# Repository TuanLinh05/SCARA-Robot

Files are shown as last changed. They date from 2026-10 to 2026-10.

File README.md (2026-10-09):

# SCARA Drawing Robot

A 2R + Z pen-drawing robot with STM32/Zephyr firmware, a Python Cartesian GUI, and MATLAB/Simulink + Webots models.

[English](#english) | [Tiếng Việt](#tieng-viet)

<p align="center">
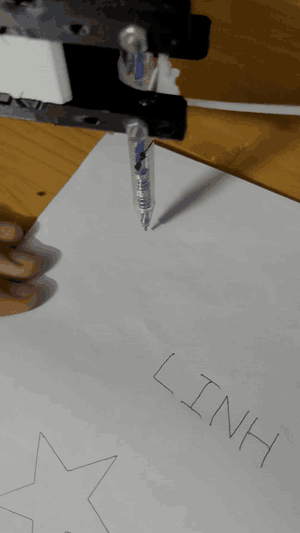
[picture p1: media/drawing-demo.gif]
Real SCARA robot drawing a six-petal flower beside earlier LINH and star drawings
  
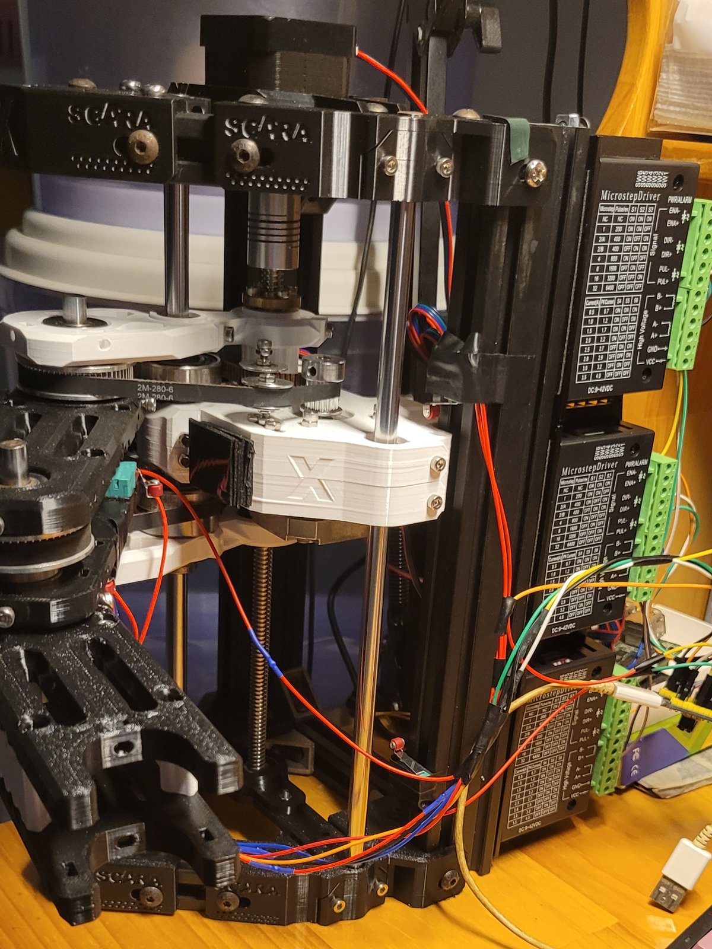
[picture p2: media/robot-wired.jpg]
Assembled X-SCARA frame, belt-driven arms, vertical lead screw, and three stepper drivers
  
</p>

The checked-in drawing demo is shown at 2x speed. [Original video](media/drawing-demo.mp4) | [Side view](media/robot-side-1.jpg) | [Driver reference photo](media/tb6600-driver.jpg).

SCARA system diagram showing GUI protocol 5, STM32 firmware R9, TB6600 drivers, six limit switches, and separate MATLAB/Webots simulation

## English

This HPMR course project (HK261) controls a SCARA robot that draws shapes and text on paper. Two rotary joints position the pen in XY and a vertical lead-screw axis raises or lowers the arm assembly. The PC performs kinematics and path planning; the STM32 emits coordinated step pulses and handles homing, limits, and communication faults.

**The frame and arm mechanics originate from [madl3x/X-SCARA](https://github.com/madl3x/x-scara/tree/master), GPL-3.0.** The STL files, mechanical BOMs, and assembly images in `Hardware/arm`, `Hardware/frame`, and `Hardware/3D Print` retain that attribution. This project's additions include firmware, GUI, simulation, and a Deli EG118 pen holder fitted to the reference geometry.

### Current components

| Component | Current version / role |
| --- | --- |
| Physical controller | STM32F103C8 Blue Pill, USB CDC, Zephyr 3.7 |
| Firmware | `SCARA_CART_NC_HOME_V5_R9`, protocol 5 |
| Desktop GUI | R14, Python 3.12 + Tkinter + pyserial |
| Stepper system | Three NEMA 17 motors and TB6600 STEP/DIR drivers |
| Homing | Six COM-NC limit switches, two per axis |
| Mechanical defaults | L1/L2 98 mm, Z lead 2 mm/revolution, configured microsteps Z/J1/J2 = 16/8/8 |
| Simulation | Analytical MATLAB/Simulink model and a separate Webots rigid-body model |

Mechanical numbers are **configuration defaults**, not measurements of every assembled robot. The real robot has no encoder-based position feedback. Its displayed Cartesian position is derived from the firmware's emitted pulse counts.

### What the system does

- Cartesian jogging, forward/inverse kinematics, reach checking, mechanical-model editing, and test point sequences.
- Shape/text library including BK, LINH, THOA, flower, star, heart, circle, ellipse, square, triangle, and rhombus.
- Whole-stroke preflight before uploading `PATH` / `SEG` / `GO` commands to a 32-segment firmware FIFO.
- Coordinated three-axis DDA step generation using a 1 MHz TIM2 timebase and fixed-point velocity profiles. The timebase is not a 1 MHz motor step rate.
- HOME/CALIB sweeps and a measured elbow-coupling probe; GPIO checks, soft limits, USB/heartbeat monitoring, and buffer-underrun handling.
- JSONL session logging and offline drawing audits.
- A `--demo` GUI mode that uses a simulated link without opening a real COM port.

### Repository map

| Path | Contents |
| --- | --- |
| [Firmware/ScaraCartesian](Firmware/ScaraCartesian) | Active Zephyr source, host tests, build tools, and supplied HEX/BIN |
| [Firmware/Ref](Firmware/Ref) | Original STM32CubeIDE/HAL project retained as reference |
| [Software/src](Software/src) | GUI, kinematic model, protocol, path planning, shapes, logs, audits |
| [Software/tests](Software/tests) | Python tests and GUI smoke checks using simulated ports |
| [Software/packaging](Software/packaging) | R14 PyInstaller specification |
| [Simulation/common](Simulation/common) | Shared SI parameters, CSV trajectories, converted meshes, provenance |
| [Simulation/matlab](Simulation/matlab) | MATLAB app, dynamics/control modules, editable Simulink model |
| [Simulation/webots](Simulation/webots) | World, PROTOs, Python controller, builder, offline checks |
| [Hardware](Hardware) | X-SCARA print files/BOMs/assembly images and EG118 holder |
| [Doc](Doc) | Firmware review and discussion of drawing errors |
| [media](media) | Photos and drawing demonstration of the physical robot |

### Try the GUI without hardware

From the repository root on Windows, with Python 3.12 and Tkinter available:

```powershell
git clone https://github.com/TuanLinh05/SCARA-Robot.git
cd SCARA-Robot
py -3.12 -m pip install -r Software\requirements.txt
py -3.12 Software\src\cartesian_nc_control.py --demo
```

The runtime requirement file pins `pyserial==3.5`; Tkinter is part of the Python environment. Demo mode lets you inspect the GUI flow without serial hardware, but it does not validate motor behavior or drawing accuracy.

For the physical connection, omit `--demo`:

```powershell
py -3.12 Software\src\cartesian_nc_control.py
```

Alternatively, `Software/Run_Cartesian_GUI.bat` uses an existing R14 EXE if present, otherwise tries a configured Zephyr Python environment and then `py -3`. A fresh clone does not include `Software/dist`.

To package the GUI from the root:

```powershell
.\Software\Build_Cartesian_NC_GUI.ps1 -Python python
```

The script can install its build dependencies into `Software/.packaging` and produces `Software/dist/SCARA_Cartesian_NC_v5_R14`. Keep the EXE and its `_internal` directory together. See [Software/README.md](Software/README.md) for configuration/log locations and the module organization.

### Wiring

The TB6600 input arrangement is common-cathode: **PUL-, DIR-, and ENA- connect to shared GND**. Check the actual driver's input characteristics and current/microstep settings against your board and motors.

| Axis | PUL+ | DIR+ | ENA+ | DIR HIGH-end switch | DIR LOW-end switch |
| --- | --- | --- | --- | --- | --- |
| Z | PA0 | PA1 | PA2 | PA3, top | PA4, bottom |
| J1 | PA8 | PB15 | PB14 | PB0 | PB1 |
| J2 | PA6 | PA7 | PB13 | PB10 | PB11 |

The [Zephyr overlay](Firmware/ScaraCartesian/app.overlay) configures ENA outputs active LOW. Switches use **COM -> GND, NC -> GPIO**, with internal 3.3 V pull-ups; NO is unused. Normal closed wiring reads LOW, while an actuated switch or open wire reads HIGH.

USB CDC uses the Blue Pill's micro-USB port: PA11 D-, PA12 D+. The GUI opens the virtual COM port at the configured 115200 baud; no separate USB-UART console is used by the active firmware.

Assembly resources: [print list](Hardware/3D%20Print/README.md), [arm BOM](Hardware/arm/BOM.md), [frame BOM](Hardware/frame/BOM.md), and [EG118 pen holder](Hardware/Pen_Holder_EG118/README.md). The print collection is organized as 14 frame parts, 23 arm parts, and one test part.

### Firmware build and supplied images

The current images are [SCARA_Cartesian_NC_Home_v5_R9.hex](Firmware/ScaraCartesian/Hex/SCARA_Cartesian_NC_Home_v5_R9.hex) and [the matching named BIN](Firmware/ScaraCartesian/Hex/SCARA_Cartesian_NC_Home_v5_R9.bin). The documented flash base is `0x08000000`; use an ST-Link/programmer configured for the actual STM32F103C8 board.

The source build expects Zephyr 3.7, Zephyr SDK 0.16.8, CMake, Ninja, and a Python/Zephyr workspace. The PowerShell helper accepts installation-path overrides:

```powershell
# Example paths: replace with your Zephyr workspace and SDK locations.
.\Firmware\ScaraCartesian\tools\build.ps1 `
  -ZephyrRoot D:/zephyrproject `
  -SdkRoot D:/zephyr-sdk/zephyr-sdk-0.16.8 `
  -BuildDirectory build_refactor -SkipExport
```

It builds board `stm32_min_dev@blue` and creates/checks a `scara_cartesian_workspace` junction under the Zephyr workspace to avoid paths with spaces. `-SkipExport` leaves the supplied `Hex` directory untouched; without it, the helper exports new HEX/BIN images there. Read [the firmware guide](Firmware/ScaraCartesian/README.md) before building or programming a board.

The GUI parser requires firmware build `SCARA_CART_NC_HOME_V5_R9` and protocol-5 status. A connected port alone does not establish firmware compatibility.

### Home, calibration, and drawing

1. Connect the correct COM port and confirm the firmware tag.
2. Review **Cơ khí** (Mechanics): link lengths, lead, microsteps, switch angles, direction signs, and tool offset must reflect the assembled robot.
3. Use **HOME / CALIB** to establish a reference. The routine scans Z/J2, probes J1-to-J2 coupling, scans J1 with compensation, then finishes the joint reference and park position.
4. Bring the pen just into contact and capture/confirm **Z giấy** (paper Z).
5. Choose **Thư viện hình & chữ** (Shape & text library), set size/center, and run **Chạy khô** (dry run) before drawing.
6. Following STOP/Esc, a reset, communication failure, limit fault, or loss of reference, HOME again before further motion.

Default `positive_high=[true,true,false]` accounts for J2's direction convention. Do not reverse signs without checking the mechanism. `tool_offset_mm=[x,y]` represents pen-tip offset from the end of L2; avoid counting the same offset in both L2 and this vector. Save mechanical changes and HOME again.

Calibration measures pulse travel and coupling. **It does not discover the true physical switch angles, link lengths, pen deflection, or missed motor steps.** Enter measured geometry instead of assuming the nominal ±90-degree switch positions are exact.

The firmware checks switch state on pulse edges, enforces soft limits, and uses a 350 ms heartbeat watchdog. Motion/arm paths are capped at 1600 pulses/s; Z calibration has a separate ceiling. These are code limits, not verified speed/accuracy specifications. Faults invalidate the reference and do not automatically resume a job.

### MATLAB/Simulink and Webots

Both models use [Simulation/common/config/scara.json](Simulation/common/config/scara.json) and shared drawing CSVs. Simulation parameters use SI units; `example_drawing.csv` uses `x_mm,y_mm,pen`, with each row's pen state applying to the segment from the previous row.

| Environment | Entry point | Requirements / limits |
| --- | --- | --- |
| MATLAB | Set Current Folder to `Simulation/matlab`, run `run_scara` | Base MATLAB supports the app/analytical model; Robotics System Toolbox and Simscape Multibody are not required |
| Simulink | `startup_scara; out=scara_simulink('flower');` | Simulink is required for the `.slx` model |
| Webots | Open `Simulation/webots/worlds/scara_draw.wbt`, then Run | Python 3 standard-library controller; no ROS or NumPy requirement |

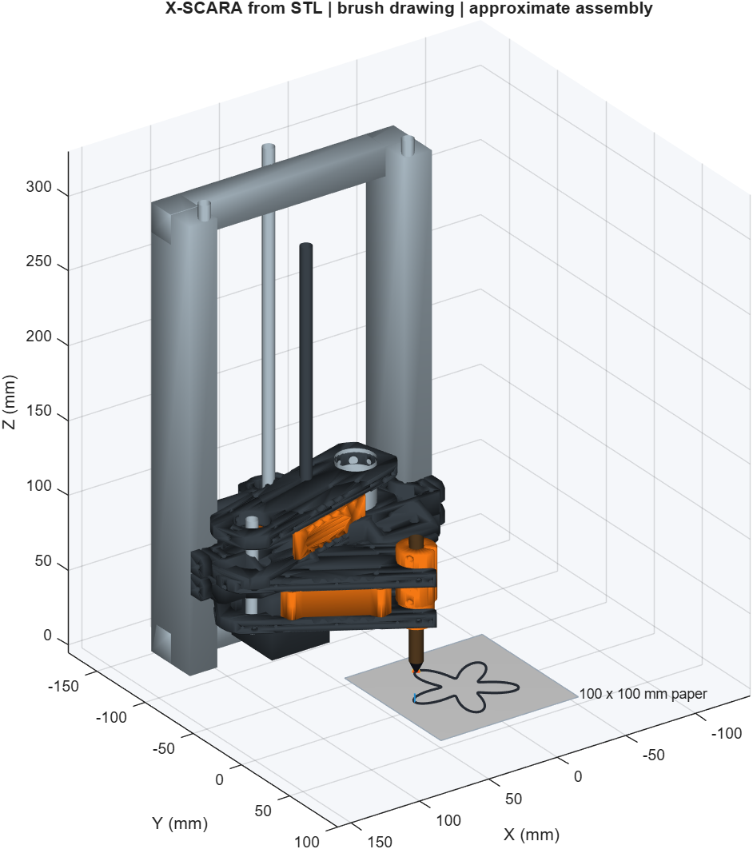
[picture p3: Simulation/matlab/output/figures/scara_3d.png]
Existing MATLAB simulation render of the X-SCARA arm and drawing surface


The MATLAB guide records execution on R2026a Update 2. Webots assets use the R2025a format; the checked-in guide reports offline/mock validation and leaves actual Webots physics execution unconfirmed. Offline checks are not evidence of a successful physical simulation run.

Webots `config/demo.json` selects `flower`, `circle`, `square`, or `csv`, and `position` or `pid` control. MATLAB analytical dynamics and Webots rigid-body/contact dynamics are different plants. Mesh geometry, inertias, simplified collisions, and brush stiffness/friction need calibration before comparing with hardware.

### Checks, logs, and accuracy limits

Existing verification entry points, from the repository root:

```powershell
# Host C firmware harness, then software tests; GUI checks use simulated ports.
.\Verify_SCARA.ps1 -Python python -Gcc gcc -Gui

# Webots offline checks; this does not launch the Webots simulator.
python -m unittest discover -s Simulation/webots/tests -v
```

The host firmware checks require GCC. The scripts may generate build/cache files. These commands are available to developers; no runtime tests or hardware operation are implied by this README update.

To inspect a saved session without opening COM:

```powershell
python Software/src/cartesian_nc_audit.py path/to/session.jsonl --out Software/reports/drawing_audit
```

The logs describe commands, timing, queue state, and pulse-coordinate telemetry. They cannot detect physical missed steps, belt backlash, paper movement, or pen flex. A correct final pulse count does not prove that the pen reached the requested point.

For distorted drawings, measure switch angles, motor/DIP settings, link lengths, and tool offset; compare lower and higher speeds with light pen pressure; inspect belt tension and holder rigidity. The [dated firmware review](Doc/Danh_gia_Firmware_SCARA.md) and [drawing audit](Software/reports/drawing_audit_20261008.md) provide diagnostic context. Their pulse/log inferences should not be treated as direct measurements of pen accuracy or automatically applied to every configuration.

### Documentation, credits, and license

Detailed component guides are primarily Vietnamese: [firmware](Firmware/ScaraCartesian/README.md), [GUI](Software/README.md), [simulation overview](Simulation/README.md), [MATLAB](Simulation/matlab/README.md), and [Webots](Simulation/webots/README.md).

- Frame/arm STL, BOMs, and assembly images: [madl3x/x-scara](https://github.com/madl3x/x-scara/tree/master), by [@madl3x](https://github.com/madl3x), source commit `3c7c17e`, GPL-3.0.
- Simulation mesh conversions record sources/hashes in [manifest.json](Simulation/common/assets/manifest.json).
- Pen-holder source and derivative reference geometry are described in [NOTICE.txt](Hardware/Pen_Holder_EG118/NOTICE.txt) and [SOURCE_LICENSE.txt](Hardware/Pen_Holder_EG118/SOURCE_LICENSE.txt).
- `Firmware/Ref` retains generated STM32CubeMX/HAL code and STMicroelectronics notices.

The repository is released under [GNU GPL v3.0](LICENSE). Project author: [Vu Tuan Linh](https://github.com/TuanLinh05), HPMR / HK261.

## Tiếng Việt

Project môn HPMR (HK261) điều khiển robot SCARA vẽ hình/chữ lên giấy. Hai khớp quay tạo chuyển động XY, trục Z nâng/hạ cụm tay. GUI tính động học và lập đường đi; STM32 phát xung phối hợp, HOME và giám sát lỗi.

**Khung và tay robot lấy từ [X-SCARA của madl3x](https://github.com/madl3x/x-scara/tree/master), GPL-3.0.** STL, BOM và ảnh lắp ráp giữ ghi nhận nguồn này. Phần bổ sung gồm firmware, GUI, mô phỏng và giá bút EG118; mesh/giá bút có manifest và NOTICE nguồn.

### Chạy GUI và kết nối

Phiên bản hiện tại: GUI R14, firmware `SCARA_CART_NC_HOME_V5_R9`, protocol 5, Blue Pill STM32F103C8 và Zephyr 3.7. GUI dùng Python 3.12, Tkinter và pyserial 3.5.

Từ gốc repo:

```powershell
py -3.12 -m pip install -r Software\requirements.txt
py -3.12 Software\src\cartesian_nc_control.py --demo
```

`--demo` dùng cổng giả lập, không mở COM thật. Bỏ cờ này để chạy GUI kết nối robot. `Software/Run_Cartesian_GUI.bat` ưu tiên EXE đã có, rồi thử Python; bản clone mới không có `Software/dist`. Lệnh đóng gói và build firmware ở phần tiếng Anh nhận đường dẫn công cụ theo máy của bạn.

### Đấu dây và HOME

TB6600 nối chung âm PUL-/DIR-/ENA- về GND. Bảng chân đầy đủ ở phần tiếng Anh: Z dùng PA0/PA1/PA2; J1 dùng PA8/PB15/PB14; J2 dùng PA6/PA7/PB13. USB CDC qua PA11 D-/PA12 D+, không cần USB-UART riêng. Công tắc COM -> GND, NC -> GPIO kéo lên 3.3 V; bình thường LOW, chạm/hở dây HIGH.

1. Chọn COM và xác nhận firmware R9/protocol 5.
2. Kiểm tra **Cơ khí**: L1/L2, lead Z, vi bước, góc công tắc, dấu chiều và lệch đầu bút.
3. HOME / CALIB, sau đó lấy/xác nhận Z giấy khi bút vừa chạm.
4. Chọn hình/chữ, cỡ và tâm; chạy khô trước khi vẽ.
5. Dừng/Esc, mất USB/heartbeat, lỗi biên hoặc reset làm mất mốc; cần HOME lại.

L1/L2 98 mm, lead 2 mm/vòng và vi bước 16/8/8 là mặc định cấu hình. HOME đo số xung và hệ số ghép, **không tự đo góc công tắc thật hoặc vị trí ngòi bút**. Đừng cộng cùng một độ lệch vào cả L2 và `tool_offset_mm`. Sau khi đổi cơ khí, lưu rồi HOME lại.

### Mô phỏng, log và giới hạn

- MATLAB: vào `Simulation/matlab`, chạy `run_scara`; Simulink cần cho file SLX. Tài liệu ghi nhận chạy trên R2026a Update 2.
- Webots: mở `Simulation/webots/worlds/scara_draw.wbt`, nhấn Run. Controller chỉ cần thư viện chuẩn Python; world dùng format R2025a. Tài liệu hiện chỉ xác nhận kiểm tra offline/mock, chưa xác nhận chạy vật lý Webots thật.
- Hai môi trường chia sẻ tham số SI và CSV trong `Simulation/common`; mô hình động lực học/tiếp xúc khác nhau và còn dùng thông số ước lượng.
- `Verify_SCARA.ps1 -Gui` chạy harness firmware trên máy rồi các kiểm thử GUI bằng cổng giả lập; không điều khiển robot. GCC cần cho harness.
- Công cụ `cartesian_nc_audit.py` đọc JSONL mà không mở COM. Log ghi lệnh và tọa độ xung, không đo mất bước, độ rơ, bút võng hoặc giấy dịch.

Robot thật **không có encoder**. Số xung đúng không chứng minh đầu bút đã tới đúng điểm. Khi hình lệch/méo, đo lại góc biên và chiều dài/offset, kiểm tra DIP driver, đai và giá bút; so sánh tốc độ thấp/cao với lực tì nhẹ. Các kết luận trong [đánh giá firmware](Doc/Danh_gia_Firmware_SCARA.md) là ngữ cảnh chẩn đoán cho log/cấu hình tại thời điểm đó, không phải phép đo độ chính xác cho mọi robot.

Repo phát hành theo [GNU GPL v3.0](LICENSE). Giữ ghi nhận [madl3x/X-SCARA](https://github.com/madl3x/x-scara) và giấy phép nguồn khi dùng lại. Tác giả project: [Vu Tuan Linh](https://github.com/TuanLinh05), HPMR / HK261.

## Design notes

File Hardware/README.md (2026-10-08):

# Hardware

> **Nguồn:** khung và tay robot lấy từ dự án mã nguồn mở
> [madl3x/x-scara](https://github.com/madl3x/x-scara/tree/master)
> (tác giả [@madl3x](https://github.com/madl3x), commit `3c7c17e`, giấy phép GPL-3.0).
> Mọi file STL, BOM và ảnh trong `arm/`, `frame/`, `3D Print/` thuộc dự án đó;
> nhóm chỉ sắp xếp lại theo màu/số lượng in và dịch hướng dẫn.

| Thư mục | Nội dung | Nguồn |
| --- | --- | --- |
| [`frame/`](frame) | STL khung, [BOM](frame/BOM.md), ảnh lắp ráp | X-SCARA |
| [`arm/`](arm) | STL tay (base, shoulder, elbow, endstop), [BOM](arm/BOM.md), ảnh lắp ráp | X-SCARA |
| [`3D Print/`](3D%20Print) | Cùng các STL trên, xếp theo màu và số bản cần in | X-SCARA (sắp xếp lại) |
| [`Pen_Holder_EG118/`](Pen_Holder_EG118) | Giá kẹp bút Deli EG118: SCAD, Python, STL | Tự thiết kế, dẫn xuất từ STL X-SCARA |

Thông tin cơ khí đầy đủ và bản thiết kế mới nhất: xem repo gốc
[madl3x/x-scara](https://github.com/madl3x/x-scara/tree/master).

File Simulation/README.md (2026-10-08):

# Mô phỏng X-SCARA vẽ bằng bút lông

Hai môi trường dùng chung hình học, tham số SI và CSV quỹ đạo. MATLAB/Simulink
dùng mô hình giải tích để nghiên cứu thuật toán; Webots dùng vật lý vật rắn,
tiếp xúc đầu bút và giấy, cùng thiết bị Pen để hiển thị nét.

## Tìm file nhanh

```text
Simulation/
├── common/
│   ├── config/scara.json              Thông số robot/bút dùng chung
│   ├── trajectories/                 CSV đường vẽ
│   └── assets/                       Mesh theo khâu, giấy, nguồn/giấy phép
├── matlab/
│   ├── run_scara.m                    Mở giao diện MATLAB
│   ├── startup_scara.m                Thêm đường dẫn + đặt cache
│   ├── config/                       Đọc tham số chung
│   ├── src/                          kinematics, dynamics, control,
│   │                                 trajectory, simulation, io, visualization
│   ├── simulink/models/              scara_brush.slx
│   ├── examples/                     So sánh PID, đọc log Webots
│   ├── tests/                        Kiểm chứng MATLAB/Simulink
│   └── output/                       figures, data, logs, validation, cache
└── webots/
    ├── worlds/scara_draw.wbt          Mở file này trong Webots
    ├── protos/                       Robot SCARA và mặt giấy
    ├── controllers/scara_draw/       Entry point + core/ thuật toán
    ├── config/demo.json              Chọn hình, chế độ điều khiển, màu mực
    ├── tools/                        Tạo lại dự án, kiểm tra offline
    ├── tests/                        Động học, điều khiển, cấu trúc, I/O
    └── output/                       runs/<thời điểm>/, validation/
```

## Chạy Webots

1. Cài Webots và Python 3. Không cần NumPy hay ROS cho controller này.
2. Mở [webots/worlds/scara_draw.wbt](webots/worlds/scara_draw.wbt) bằng **File → Open World**.
3. Nhấn **Run**. Robot di chuyển đến điểm đầu, hạ bút, vẽ hoa rồi nhấc bút.
4. Sửa [webots/config/demo.json](webots/config/demo.json), sau đó **Reset/Reload**
   để thử `circle`, `square`, `csv` hoặc `control_mode: "pid"`.

Xem [hướng dẫn Webots](webots/README.md) để chỉnh thuật toán, đọc log và debug.
World/PROTO dùng header `R2025a`, bản ổn định chính thức được kiểm tra ở thời điểm
tạo dự án. Không cần đổi header chỉ vì cài một bản mới hơn. Máy hiện chưa có
Webots nên chưa xác nhận khởi chạy hoặc vật lý trên bản 2026 bạn định cài.

## Chạy MATLAB/Simulink

Trong MATLAB, chuyển Current Folder đến `Simulation/matlab` rồi chạy:

```matlab
run_scara
```

Hoặc `startup_scara; out=scara_simulink('flower');`. File SLX nằm trong
`matlab/simulink/models/scara_brush.slx`, tự thêm đường dẫn khi mở/chạy trực tiếp.
Xem [hướng dẫn MATLAB](matlab/README.md).

## Các điểm cần biết trước khi dùng kết quả trong bài tập

- Hình dáng tay lấy từ 11 instance STL trong `Hardware/arm/STL`, gom thành
  5 mesh có đơn vị mét. Chiều dài hai khâu mặc định 98 mm. Tầng lắp ráp Z,
  thành bên, khung, motor, bút và giá kẹp còn là xấp xỉ.
- Mô hình có hai khớp quay và trục Z nâng cả cụm tay. Webots có thêm khớp
  đàn hồi thụ động ở đầu bút, GPS đầu bút, cảm biến lực và encoder.
- Khối lượng, quán tính, ma sát, giới hạn khớp/lực và độ đàn hồi cần hiệu chỉnh
  bằng đo đạc. STL chỉ cung cấp bề mặt; không tự chứa các thông số này.
- Bút dùng tiếp xúc cầu nhỏ + lò xo để nghiên cứu lực tì. Nét Pen có độ rộng
  cố định; chưa mô phỏng từng sợi bút, mực loang hoặc nét thư pháp.
- Collision dùng hình đơn giản và `selfCollision FALSE`; chưa kiểm chứng tránh
  va chạm chi tiết. Đai/crosstalk chỉ được quy đổi tọa độ A/B trong log, chưa
  được mô phỏng như truyền động đàn hồi hay mô hình điện động cơ bước.

## Trạng thái kiểm chứng

MATLAB/Simulink đã chạy thực tế trên R2026a Update 2 sau khi sắp xếp lại thư mục.
Kiểm thử Webots offline kiểm tra thuật toán, đối chiếu MATLAB, I/O controller,
trường node theo nguồn R2025a, đường dẫn mesh và tính nhất quán khớp/quán tính.
Kiểm thử mock không mô phỏng vật lý Webots. Kết quả nằm trong `output/validation`
của từng môi trường; phần chạy Webots thật còn chờ cài phần mềm.

Nguồn thiết kế: [madl3x/x-scara](https://github.com/madl3x/x-scara), GPL-3.0.
Mesh chuyển đổi giữ manifest nguồn, mã băm và giấy phép trong `common/assets`.
Tài liệu [Pen](https://cyberbotics.com/doc/reference/pen),
[khớp](https://cyberbotics.com/doc/reference/jointparameters),
[TouchSensor](https://cyberbotics.com/doc/reference/touchsensor) và
[bản phát hành Webots](https://github.com/cyberbotics/webots/releases).

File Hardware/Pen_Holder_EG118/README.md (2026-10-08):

# Giá giữ bút Deli EG118 cho đầu SCARA — bản 1

Đã dựng theo hai STL `Arm_Elbow_Plate_Top_1.0.0.stl`, `Arm_Elbow_Plate_Bottom_1.0.0.stl` và chiều cao 18 mm của sidewall trong `Hardware/arm`. Thân bút lấy theo số đo bạn cung cấp: **khoảng 9 mm**, có thể sai ±0,5 mm.

Giá gồm thân gá vào hai ngàm chữ U và một nắp ép bút vào rãnh V 90°. Hai mặt V cùng mặt ép tạo ba hướng tiếp xúc, giúp căn bút thẳng. Hai ốc xuyên ngang giữ giá vào robot; bốn ốc riêng siết nắp giữ bút. Có thể nới nắp để chỉnh độ thò ngòi hoặc thay bút. Khoảng đường kính đã kiểm tra hình học: **8,5–9,5 mm**.

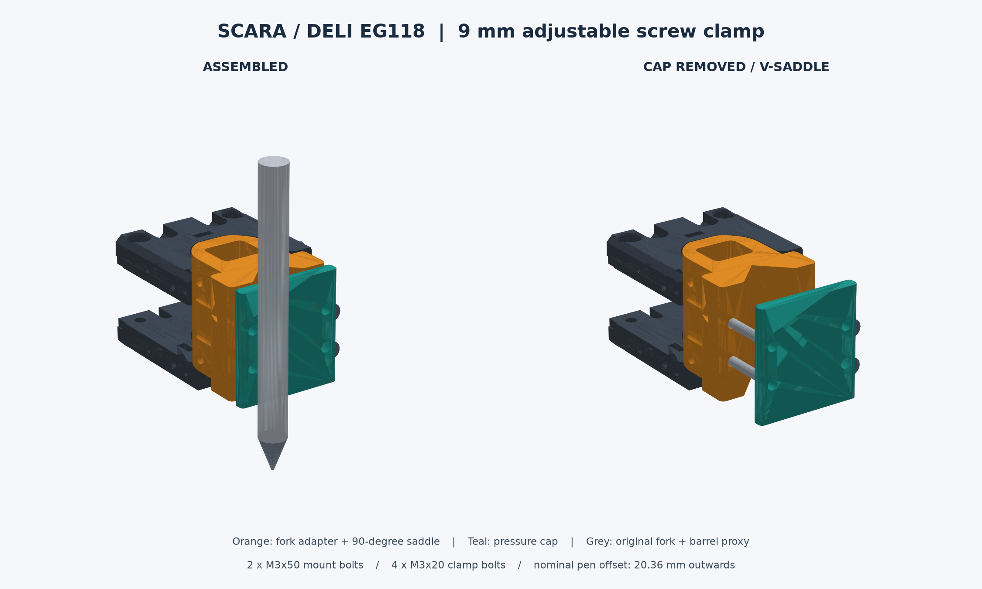
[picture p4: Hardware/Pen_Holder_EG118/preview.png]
Hình lắp ráp


## File để in

| File trong `STL/` | Số lượng | Công dụng | Kích thước đặt trên bàn in, mm |
| --- | ---: | --- | --- |
| `01_Fork_Adapter_V_Saddle.stl` | 1 | Thân gá và rãnh V | 34 × 34,6 × 36 |
| `02_Pressure_Cap.stl` | 1 | Nắp ép bút | 34 × 36 × 4 |
| `03_Test_Adapter_8mm.stl` | 1, nên in trước | Mẫu thấp để thử ngàm, lỗ ốc và độ vừa bút | 34 × 34,6 × 8 |
| `04_Test_Cap_8mm.stl` | 1, nên in trước | Nắp cho mẫu thử | 34 × 8 × 4 |

STL dùng **mm**, đã đặt đáy ở Z=0 và hướng in sẵn. Giữ tỷ lệ **100%** trong slicer. In mẫu 03/04 trước; mẫu thử chỉ dùng kiểm tra độ vừa, không dùng vẽ trên robot.

`assembly_reference.glb` và `assembly_reference.stl` là hình tham khảo ở tọa độ lắp ráp. **Chỉ in từng file trong `STL/`.** Bút trong hình là hình trụ minh họa đường kính, không mô phỏng chi tiết thân hoặc chiều dài EG118.

## Ốc và đai ốc

| Vật tư | Số lượng | Chỗ dùng |
| --- | ---: | --- |
| Ốc đầu trụ M3×50 | 2 | Xuyên qua hai tai ngàm robot và thân gá |
| Đai ốc M3 | 2 | Giữ hai ốc gá, ở mặt ngoài ngàm |
| Long đen M3 | 4 | Đệm hai phía ngoài ngàm |
| Ốc đầu trụ M3×20 | 4 | Siết nắp ép bút |
| Đai ốc M3, ngang cạnh khoảng 5,5 mm, dày ≤2,6 mm | 4 | Gài vào hốc lục giác ở phía sau thân rãnh V |

Chiều dài ốc dự kiến theo STL. Kiểm tra trên robot thật: ren phải đi hết đai ốc và nhô ra khoảng 1–2 vòng. Nếu ngàm có sẵn đai ốc chôn, tháo đai ốc nằm trên đường xuyên của ốc dài để không cản lắp. Nắp ép dùng đai ốc kim loại; không cần tarô nhựa.

## Kích thước giao tiếp và phần cần đo

| Kích thước | Giá trị / căn cứ |
| --- | --- |
| Khoảng rộng giữa hai tai chữ U | 25,5 mm, đo từ STL |
| Bề rộng phần chèn của giá | 24,8 mm, chừa tổng 0,7 mm |
| Mặt phẳng đáy trong của cung ngàm | Cách tâm cung 11,75 mm, đo từ STL |
| Mặt phẳng đáy phần chèn | Cách tâm cung 11,4 mm |
| Bề dày mỗi tấm ngàm | 9 mm, đo từ STL |
| Khoảng trống giữa hai tấm | **Giả định 18 mm**, theo sidewall |
| Tổng chiều cao cụm | **Giả định 36 mm** = 9 + 18 + 9 |
| Khoảng cách tâm hai ốc ngang | **25 mm**, theo cách lắp hai tấm đối mặt |
| Rãnh cho ốc gá | Rộng 3,6 mm, cao 6 mm; tâm tại Z=5,5 và 30,5 mm |
| Lỗ ốc nắp ép | Ø3,4 mm; X=±13 mm; Z=12 và 24 mm |
| Hốc đai ốc của nắp | Ngang cạnh 5,8 mm, sâu 2,6 mm |

**Đo lại chiều cao cụm và khoảng cách tâm hai ốc ngang trên robot đã lắp.** Ảnh không đủ xác định chính xác khoảng cách này. Rãnh đứng cho phép dịch tâm ốc khoảng ±1,2 mm so với danh định; nếu khác nhiều hơn, chỉnh `mount_centers_z`/`height` trong SCAD trước khi in thân hoàn chỉnh.

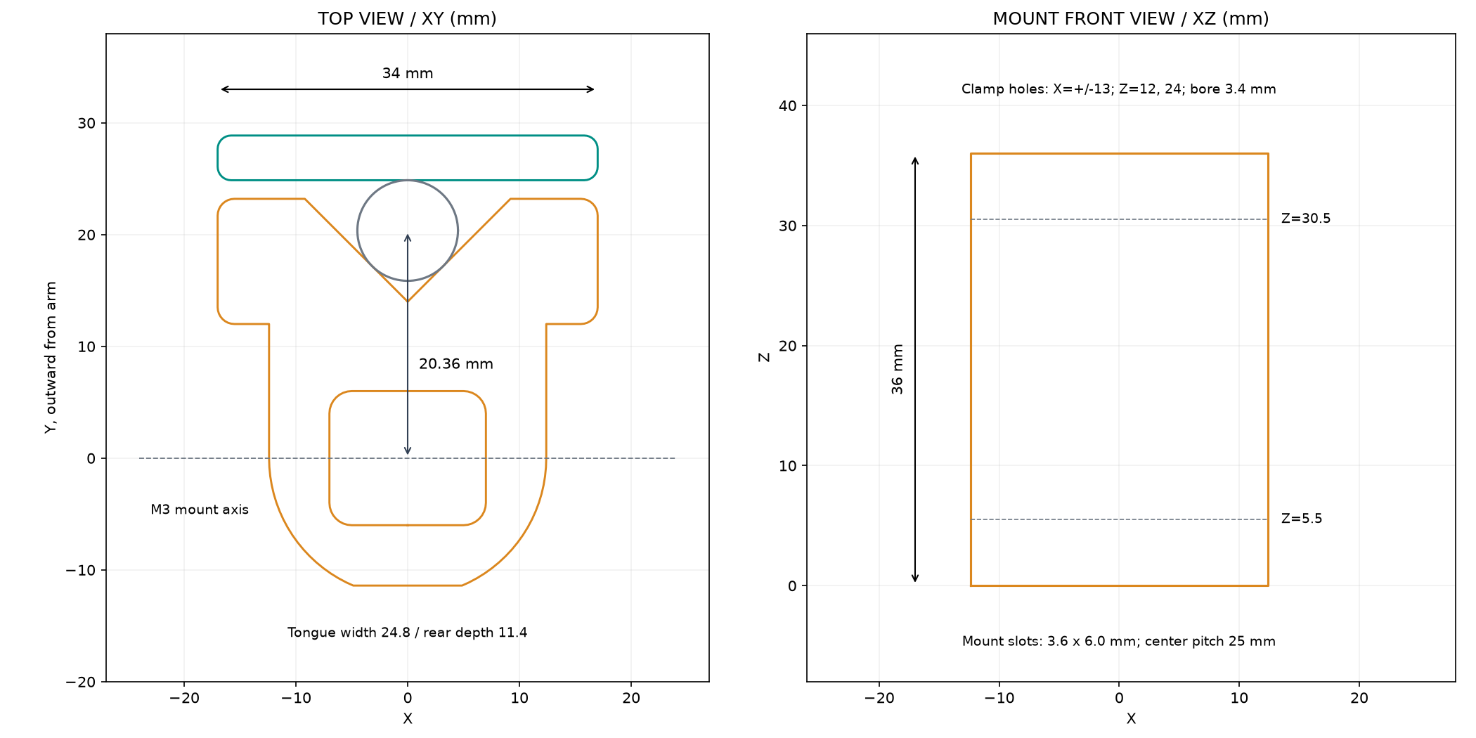
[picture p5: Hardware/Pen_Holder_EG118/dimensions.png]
Bản vẽ kích thước


## In và thử độ vừa

- Có thể dùng PETG hoặc PLA. Gợi ý khởi đầu: lớp 0,2 mm, 4 vách, 5 lớp đáy/nóc, infill 35–45%. PETG phù hợp nếu tháo lắp thường xuyên; PLA cũng dùng để thử và vẽ tải nhẹ.
- Thân chính in đứng theo file. Nắp in nằm trên mặt ngoài phẳng như đã xuất. Các lỗ ngang nhỏ có thể in cầu; kiểm tra preview slicer, thường không cần support. Chỉ thêm support cục bộ nếu máy của bạn in cầu kém.
- Làm sạch ba via. Thử ốc M3 qua lỗ bằng tay; nếu cần, làm sạch lỗ nắp bằng mũi 3,2–3,4 mm. Không ép ốc vào khi kẹt.
- Đưa mẫu 03 vào một ngàm để thử độ vừa và đường đi của ốc ngang. Tháo mẫu khỏi robot rồi lắp nắp 04 với hai đai ốc và hai ốc M3×20 để thử kẹp bút trên bàn. Cách này tránh đầu ốc mẫu thấp vướng tấm ngàm.
- Chọn đoạn thân tròn, thẳng, không có kẹp áo hoặc nút bấm. Bút phải tì vào cả hai mặt V. Sai số đường kính được bù bằng vị trí nắp, không cần ép bút vào một lỗ kín.
- Khi mẫu ổn, in 01 và 02. Nếu phần chèn quá chặt, giảm `fork_radius` khoảng 0,1–0,2 mm và thử lại. Giữ nguyên kích thước lỗ ốc; tránh scale toàn bộ mô hình.

## Lắp lên robot

1. Tháo ốc ngang ở đầu ngàm để đưa thân giá vào từ phía mở của chữ U. Rãnh V và nắp quay ra ngoài đầu tay robot.
2. Căn hai rãnh của thân giá với hai lỗ ngang trên robot. Luồn hai ốc M3×50, thêm long đen và đai ốc ở ngoài. Siết đều vừa đủ để giá không xoay hoặc trượt; thử bằng tay trước khi chạy.
3. Gài bốn đai ốc vào các hốc sau thân rãnh V, tại hai hàng Z=12 và 24 mm. Có thể dùng một chấm băng dính tạm giữ đai ốc khi lắp.
4. Đặt bút vào V, bấm ngòi ra, lắp nắp và bốn ốc M3×20. Siết luân phiên bốn ốc, giữ nắp song song với thân giá. Chỉnh độ thò ngòi trước khi siết chặt.
5. Với bút Ø9 mm, khe giữa tai nắp và thân khoảng **1,66 mm**; Ø8,5–9,5 mm cho khe khoảng **1,06–2,27 mm**. Không cần siết cho hai tai chạm nhau. Dừng khi bút không trượt dưới lực viết nhẹ; siết quá mạnh có thể làm biến dạng thân bút.
6. Cho robot chạy chậm và kiểm tra khoảng hở thực tế tại các tư thế sẽ vẽ. Đặt mặt giấy phẳng và chỉnh Z để ngòi vừa chạm giấy, sau đó tăng lực tiếp xúc từng ít một.

## Hiệu chỉnh vị trí ngòi

Hai ốc gá ngang đi qua vùng tâm ngàm nên bút được đưa ra phía trước để tránh chúng. Với thân Ø9 mm, trục bút cách tâm ngàm **20,364 mm theo hướng ra ngoài của tay robot**, X=0. Rãnh V làm vị trí này thay đổi nhẹ theo đường kính:

`độ lệch Y = 14 + đường kính thân / √2` (mm).

Trong khoảng 8,5–9,5 mm, độ lệch Y là **20,010–20,718 mm**. Đo ngòi thực sau khi siết và hiệu chỉnh offset công cụ/IK theo quy ước tọa độ phần mềm bạn đang dùng. Nếu IK của bạn đang lấy L2=98 mm từ khớp khuỷu đến tâm ngàm và đầu bút nằm thẳng theo hướng tay, khoảng cách đến trục bút danh định thành khoảng **118,364 mm**. Không cộng cả độ lệch này vào L2 và tool offset cùng lúc.

Giá này **giữ bút cứng, không có lò xo bù lực theo Z**. Độ đều nét còn phụ thuộc mặt giấy, độ rơ robot, chỉnh Z và lực viết. Hiệu chỉnh lại Z sau khi thay bút hoặc đổi độ thò ngòi.

## File nguồn và kiểm tra

- `EG118_Holder.scad`: nguồn CAD tham số. Mở bằng OpenSCAD, chọn `part="base"` hoặc `"cap_print"`, render rồi export STL. Chọn `"test_base"`, `"test_cap_print"` để in thử. `"assembly"` để xem lắp ráp. Nguồn SCAD chưa được biên dịch trong môi trường tạo file; STL cung cấp được sinh và kiểm tra bằng Manifold.
- `build_holder.py` và `requirements.txt`: sinh lại STL, hình xem trước và báo cáo. Chạy `python build_holder.py --pen-diameter 9` trong thư mục này sau khi cài dependencies. Script hiện kiểm tra bộ gá 36 mm; các sửa đổi khoảng cách ngàm trong SCAD cần kiểm tra lại trên robot thật.
- `validation.json`: bốn STL đều kín, hướng mặt nhất quán và mỗi file có một khối liền. 13 kiểm tra hình học đã qua: giao cắt giá với hai STL ngàm bằng 0; đường đi hai ốc gá và bốn ốc kẹp thông; bút trụ 8,5 / 9 / 9,5 mm vừa giữa các mặt ép.
- Các kiểm tra trên là kiểm tra hình học theo cách lắp giả định, **chưa phải kiểm chứng bản in hoặc lực siết thực tế**. Chưa đánh giá tải động, độ bền lâu dài hay toàn bộ hành trình robot.
- `source_geometry.png`, `plate_sections.png`, `interface_detail.png`: hình dùng đối chiếu với file gốc.

Thông tin Deli EG118: [trang sản phẩm Deli Việt Nam](https://delivietnam.com.vn/san-pham/but-gel-bam-deli-eg118-cong-nghe-muc-sieu-muot-giam-ma-sat). Thông số 0,5 mm trên trang là **ngòi viết**; đường kính thân dùng thiết kế này lấy từ số đo 9 mm của bạn.

Các mesh ngàm gốc dùng làm tham khảo thuộc X-SCARA của madl3x, nguồn và GPL-3.0 được ghi trong `Simulation/common/assets/manifest.json`. Bản xem trước và cảnh 3D có chứa hình học tham khảo từ các mesh đó; xem `SOURCE_LICENSE.txt` và `NOTICE.txt`.

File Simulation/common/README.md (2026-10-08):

# Dữ liệu chung MATLAB và Webots

- `config/scara.json`: nguồn tham số số duy nhất, đơn vị m, rad, s, kg, N, Nm.
- `trajectories/example_drawing.csv`: cột `x_mm,y_mm,pen`; trạng thái pen trên
  hàng i áp dụng cho đoạn từ hàng i-1 đến i. `0` nhấc, `1` hạ bút để vẽ.
- `assets/meshes`: STL đã chuyển từ mm sang m, đặt về hệ tọa độ từng khâu.
- `assets/manifest.json`: 11 instance STL gốc, dấu trục, dịch chuyển, nguồn,
  mã băm SHA256, giấy phép và mức xấp xỉ lắp ráp.
- `assets/textures/paper.png`: giấy trắng cho Webots Pen, không lưu nét chạy
  mô phỏng vào file PNG gốc.

## Tham số để debug

| Nhóm | Trường trong scara.json | Ý nghĩa |
| --- | --- | --- |
| Hình học | L1, L2, base, toolOffset, paperHalfSize | Chiều dài, tâm vai, lệch đầu bút, khổ giấy |
| Giới hạn | jointLimits, zLimits, singularityMargin | Góc S/E và chiều cao đầu bút tự do; giới hạn làm việc giả định |
| Truyền động | elbowCrosstalkRatio, stepsPerDegree, stepsPerMeterZ | Quy đổi A=S, B=E+S/3 và tọa độ vi bước theo firmware |
| Động lực học | mass1, mass2, massTool, zMass, rotorInertia | Khối lượng/quán tính ước lượng; zMass bao gồm mọi phần được nâng |
| Ma sát | viscous, coulomb, brushMu | Cản nhớt, ma sát khớp và tiếp xúc bút/giấy |
| Bút | brushK, brushC, brushCompression, penLift | Lò xo/giảm chấn, độ nén đích và độ nhấc bút |
| Điều khiển | Kp, Kd, Ki, actuatorLimits, feedforward | PID; giới hạn là mô-men KHỚP và lực Z, chưa là thông số rotor |
| Thời gian | dt, gravity | Bước mô phỏng mặc định 2 ms, gia tốc trọng trường |
| Hiển thị | lineWidth0, lineWidthPerN | Webots dùng độ rộng cố định lineWidth0; quan hệ theo lực ở MATLAB là minh họa |

S/E dương quay quanh +Z; tay ở góc 0 hướng +Y. Z=0 là đầu bút **chưa biến dạng**
đúng mặt giấy. Z âm biểu diễn nén bút; Webots spring làm đầu bút thực tế nằm gần
mặt giấy, thay vì cố xuyên đầu bút vào giấy.

Sau khi đổi hình học/thông số vật lý, chạy từ thư mục gốc `Scara Robot`:

```powershell
python Simulation/webots/tools/build_project.py
python Simulation/webots/tools/validate_project.py
```

Reload world Webots. Controller kiểm tra mã băm cấu hình vật lý và từ chối
chạy khi world cũ không khớp JSON. Đổi gains PID, độ nén bút hoặc chọn đường vẽ
không cần dựng lại world. MATLAB đọc lại JSON khi gọi `scara_params`; nếu đã
đặt biến `scara_p` trong workspace, gọi `scara_setup('flower',scara_params())`
để áp dụng mặc định mới.

Đổi L1/L2 làm scale đồ họa theo Y, phục vụ thử thuật toán; chưa là thiết kế CAD
cho một robot với chiều dài mới. Khi đổi cấu hình, các fixture đối chiếu MATLAB
trong Webots tests cần tạo lại bằng `startup_scara; validate_webots_interop`.

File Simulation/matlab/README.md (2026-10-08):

# MATLAB/Simulink: X-SCARA gắn bút lông

Bộ mô phỏng ban đầu cho bài tập: hiển thị 3D từ STL có sẵn, động học/quỹ đạo vẽ,
động lực học và PID, cùng một mô hình Simulink chỉnh sửa được. Các file gốc trong
`Hardware` và `Firmware` không bị sửa.

## Chạy nhanh trong MATLAB

Mở thư mục `Simulation/matlab` trong MATLAB rồi chạy:

```matlab
run_scara
```

Cửa sổ có mô hình 3D xoay được bằng chuột, thanh chỉnh góc vai/khuỷu/Z, bốn hình
vẽ mẫu và nhập CSV. Chọn `Kinematics (IK)` để xem chuyển động lý tưởng hoặc
`PID + dynamics` để chạy vòng điều khiển. `Model feedforward` bật/tắt bù theo
mô hình; `Plot / export last run` xuất MAT và CSV vào `output/data/matlab`.
`run_scara` tự gọi `startup_scara` để thêm đường dẫn các thư mục nguồn.

Chạy thuật toán trực tiếp, không cần giao diện:

```matlab
startup_scara
p = scara_params();
ref = scara_reference('flower',p); % circle, square, bk hoặc đường dẫn CSV
out = scara_simulate(ref,p);
scara_plot(out,p);
scara_export(out,ref,p);
```

Chạy mô hình Simulink đã lưu:

```matlab
startup_scara
p = scara_params();
scara_setup('flower',p);
open_system(fullfile(p.modelsRoot,'scara_brush.slx'));
% Nhấn Run, hoặc:
out = scara_simulink('flower');
```

Để tạo lại file SLX từ mã nguồn: `build_scara_simulink`. Hàm này từ chối tạo lại
khi mô hình đang mở có thay đổi chưa lưu. MATLAB cơ bản đủ cho mô phỏng và 3D;
Simulink cần cho SLX. Đã kiểm tra trên MATLAB/Simulink R2026a Update 2. Bộ này
không cần Robotics System Toolbox hoặc Simscape Multibody.

## Vẽ chữ BK theo hình tham khảo

Chạy `run_scara`, chọn **BK** ở ô Trajectory, rồi **Run + animate**. Hoặc:

```matlab
startup_scara
[out,ref] = draw_bk(); % Mô phỏng PID, xem hình và lưu dữ liệu BK riêng
% Với Simulink:
out_sl = scara_simulink('bk');
```

Nút **Open Simulink model** dùng quỹ đạo đang chọn trong giao diện, kể cả BK.

Hình giữ tọa độ nguồn X/Y từ 0 đến 0.5: B có thân X=0 và hai nửa đường tròn
bán kính 0.125; K có thân X=0.25, giao điểm (0.25,0.25) và hai đầu chéo ở
(0.5,0.5)/(0.5,0). Các trục tọa độ trong ảnh tham khảo không là nét vẽ.
Mẫu thu nhỏ đồng dạng, đặt giữa giấy: mặc định **70 × 70 mm**, trong giấy
100 × 100 mm. Không dùng trực tiếp kích thước 0.5 m vì vượt tầm với robot.

Robot vẽ ba nét liên tục: thân + hai cung B, thân K, hai nét chéo K. Bút nhấc
6 mm giữa các nét; các đoạn dùng quintic, dừng êm ở chỗ đổi hướng. Cung B được
tính bằng sin/cos, không ghép nhiều đoạn CSV ngắn có dừng ở từng điểm.
Hình học và tốc độ nằm trong `src/trajectory/scara_bk_path.m`.

`draw_bk` lưu `output/figures/bk_drawing.png`, `bk_tracking.png` và
`output/data/matlab/bk/simulation.csv/.mat`, để giữ riêng dữ liệu mẫu này.
`validate_bk(true)` kiểm tra hình học, nhấc bút, giới hạn và đối chiếu Simulink;
báo cáo nằm trong `output/validation/bk_validation.json`.

## Thử thuật toán của bài tập

| Mục tiêu | File/hàm cần chỉnh |
| --- | --- |
| Chiều dài tay, góc giới hạn, khối lượng, ma sát, bút, gains PID | `../common/config/scara.json`, đọc bởi `config/scara_params.m` |
| Động học thuận và Jacobian | `scara_fk.m` |
| Động học ngược, nhánh nghiệm, giới hạn và kỳ dị | `scara_ik.m` |
| Quỹ đạo và nhấc/hạ bút | `scara_reference.m` |
| PID hoặc thuật toán điều khiển khác | `scara_controller.m` |
| Ma trận quán tính, Coriolis, lực tiếp xúc | `scara_dynamics.m`, `scara_accel.m` |
| Vòng điều khiển dạng sơ đồ khối | `simulink/models/scara_brush.slx` |
| So sánh PID và PID có feedforward | `compare_scara_controllers.m` |
| Vị trí các mesh trong cụm lắp ráp | `scara_meshes.m`, `scara_update.m` |

Khối MATLAB Function trong SLX gọi cùng các hàm điều khiển và động lực học như
bản MATLAB. Đổi thuật toán trong `scara_controller.m` sẽ tác động cả hai môi
trường. Đây là mô hình động lực học giải tích với khớp lý tưởng; chưa có mô hình
điện động cơ bước, bộ phát xung STM32 hay đai đàn hồi.

Ví dụ thay gain và thử ảnh hưởng tiếp xúc:

```matlab
p = scara_params();
p.Kp(1:2) = [1; 0.7];
p.brushK = 500;
p.feedforward = false;
ref = scara_reference('circle',p);
out = scara_simulink('circle',p);
```

`../common/trajectories/example_drawing.csv` có ba cột `x_mm,y_mm,pen`. Giá trị `pen` trên hàng i áp
dụng cho đoạn từ hàng i-1 đến hàng i. `pen=0` di chuyển với bút nhấc; `pen=1`
vẽ với bút hạ. Mỗi đoạn dùng thời gian quintic để dừng êm ở các nút. Khổ giấy
mẫu là 100 × 100 mm; chưa có bộ đọc SVG, xử lý ảnh hoặc tối ưu thứ tự nét.

## Hệ tọa độ và phương trình

Trong các hàm tính toán dùng mét, radian, giây, N và Nm. Giao diện/CSV dùng
mm và độ với tên cột chỉ rõ đơn vị. `q = [S; E; z]`, trong đó E là góc khuỷu
tương đối với đoạn tay thứ nhất. Gốc giấy ở giữa tờ giấy; tâm vai ở
`[0; -0.110]` m. Góc 0 hướng theo +Y; góc dương quay về -X. Quy ước dấu này
theo `x_scara_fwdk` trong mã nguồn repo.

Với đầu bút không có lệch XY:

```text
x = base_x - L1 sin(S) - L2 sin(S+E)
y = base_y + L1 cos(S) + L2 cos(S+E)
z = free_tip_height
```

`scara_ik` cũng xử lý `toolOffset`, kiểm tra bán kính với tới, vùng kỳ dị và
giới hạn khớp. Chiều dài L1/L2 mặc định 98 mm theo repo. Góc giới hạn trong bộ
mô phỏng là giá trị làm việc giả định, cần đo trên robot thật. Kiểm tra động
học không xác nhận tránh va chạm giữa các chi tiết STL.

Tọa độ điều khiển tương đương firmware:

```text
A = S
B = E + S/3
```

Tỷ số 3 và steps/degree lấy từ Configuration.h của X-SCARA, với motor 200
steps/rev và vi bước 16. A/B không phải góc rotor. CSV steps là tọa độ tuyệt
đối đã làm tròn để phân tích; chưa là luồng xung có homing/giới hạn tốc độ
để nạp vào STM32. Các mô-men trong mô phỏng là mô-men tại khớp; muốn quy đổi
về trục động cơ phải xét cả tỷ số truyền và hiệu suất.

Động lực học:

```text
M(q) qdd + C(q,qd) + friction(qd) + gravity = actuator + J' F_contact
```

Hai đoạn tay được xấp xỉ bằng thanh đồng nhất, bút bằng khối lượng tập trung.
Ma trận M có liên kết giữa hai khớp quay. Z dùng khối lượng của toàn cụm nâng;
trọng lực tác động vào Z. PID có bù trọng lực, bù mô hình tùy chọn, giới hạn
mô-men/lực và chống tích lũy sai số khi bão hòa.

Mô hình bút dùng chiều cao của đầu bút khi chưa biến dạng: z < 0 là độ nén
đầu bút/lò xo, không phải độ xuyên vào giấy. Khi z <= 0:

```text
Fn = max(0, -k*z - c*zd)
Fxy = -mu*Fn*vxy / sqrt(norm(vxy)^2 + 0.001^2)
```

Nét chỉ được ghi khi có lực tì và vị trí nằm trên giấy. Cột
`illustrative_line_width_mm` dùng quan hệ tuyến tính giả định giữa lực và
độ rộng nét. Hình vẽ hiển thị bằng đường tâm có độ dày cố định: chưa mô phỏng
biến dạng sợi bút, mực, nhòe hoặc nét thư pháp. Nếu dùng bút lông marker,
độ đàn hồi này có thể đại diện cho giá kẹp có lò xo; cần đo lại k và c.

## Độ chính xác và việc cần hiệu chỉnh

- Bốn tấm vai/khuỷu, hai bản đế, bốn thành bên và một rod hub được đọc trực
  tiếp từ STL: tổng 11 instance. Tâm lỗ XY suy ra từ mesh. Khoảng cách các
  tầng theo Z và vị trí thành bên là lắp ráp xấp xỉ.
- Thanh dẫn hướng, nhôm định hình, motor và trục dùng hình học đơn giản.
  Bút và giá kẹp là hình khái niệm, chưa là thiết kế giá kẹp để in 3D.
- Khối lượng, quán tính motor, ma sát, lực cực đại, độ cứng/giảm chấn và
  quan hệ lực–độ rộng nét là thông số ước lượng, tập trung trong một file.
- Chưa mô phỏng độ rơ, mất bước, đàn hồi đai, độ võng tay, tiếp xúc mesh
  hay va chạm. Bộ mô phỏng phù hợp để thử thuật toán ban đầu; chưa thay thế
  mô hình cơ khí được hiệu chỉnh hoặc phép đo trên robot.
- Feedforward mặc định sử dụng cùng mô hình với plant, nên sai số số học
  rất nhỏ. Không suy ra độ chính xác robot thật từ các giá trị đó. Tắt
  feedforward hoặc thay thông số/gains để phân tích độ nhạy.

Với robot vẽ, nên đặt bút thẳng đứng, có giá kẹp đàn hồi nhẹ, hiệu chỉnh tọa
độ đầu bút và mặt giấy, rồi thử nét cơ bản trước khi thử tranh. Với hình có
nét cần hướng nghiêng cố định, cần bổ sung bậc tự do đầu bút hoặc ràng buộc
quỹ đạo; cấu hình 2R+Z hiện tại không điều khiển hướng đầu bút độc lập.

## Kiểm chứng và kết quả mẫu

Chạy `validate_scara(true)` để kiểm tra:

- 100 trường hợp FK/IK, Jacobian bằng sai phân, M xác định dương và quan hệ
  năng lượng Coriolis; thêm trường hợp đầu bút lệch XY.
- Từ chối điểm ngoài tầm với, điểm kỳ dị và tâm gập không xác định.
- Lực tì bằng 0 khi nhấc, lực đàn hồi khi nén, bão hòa và chống windup PID.
- Vẽ circle/flower/square và CSV, kiểm tra sai số, giới hạn và trạng thái bút.
- Đọc STL, render mô hình và so sánh nghiệm RK4 với Simulink ode4.

`output/validation/validation.json` chứa số liệu kiểm tra. `output/figures/scara_3d.png`,
`arm_detail.png`, `tracking.png` và `simulink_model.png` là các ảnh mẫu.
`output/data/matlab/simulation.mat` giữ dữ liệu SI và tham số; CSV có cột góc, vị trí,
lực tì, sai số, mô-men và tọa độ bước để dùng trong báo cáo bài tập.

Với quỹ đạo hoa và bộ tham số mặc định, bản MATLAB và Simulink khác nhau tối đa
2.45e-15 ở các trạng thái. PID bù trọng lực có sai số XY RMS khoảng 1.1406 mm;
PID có bù mô hình khoảng 0.00015 mm trong mô hình lý tưởng này. Những giá trị
này dùng để kiểm chứng và so sánh thuật toán, không là thông số độ chính xác
của phần cứng. `output/figures/controller_comparison.png` chứa đồ thị so sánh và
`output/figures/app_ui.png` là ảnh giao diện đang chạy.

## Cấu trúc và log Webots

`src/kinematics`, `dynamics`, `control`, `trajectory`, `simulation`, `io`,
`visualization` chia hàm theo vai trò. `simulink` chứa hàm dựng/chạy SLX,
`tests` chứa kiểm chứng, `examples` chứa so sánh PID và `analyze_webots_run`.
`startup_scara` chỉ thêm thư mục nguồn và đặt cache/codegen ở `output`.

`startup_scara; analyze_webots_run` đọc CSV cảm biến do Webots xuất và vẽ
quỹ đạo, sai số, lực tì và Z. `validate_webots_interop` tạo fixture đối chiếu
FK/PID/quỹ đạo cho Python tests. Đây là trao đổi file sau chạy, chưa là đồng
mô phỏng thời gian thực. Các tham số dùng chung nằm ở `../common/config/scara.json`.

## Nguồn tham khảo

- X-SCARA, Alex Mircescu: https://github.com/madl3x/x-scara
- Cấu hình hình học và truyền động: https://github.com/madl3x/x-scara/blob/master/firmware/CONFIGURE.md
- Quy ước động học và crosstalk: https://github.com/madl3x/x-scara/blob/master/firmware/Marlin-2.0.x/Marlin/src/module/scara.cpp
- Tỷ số crosstalk: https://github.com/madl3x/x-scara/blob/master/firmware/Marlin-2.0.x/Marlin/Configuration.h
- Hướng dẫn lắp ráp và CAD: https://github.com/madl3x/x-scara/blob/master/hardware/arm/README.md
- MATLAB Function: https://www.mathworks.com/help/simulink/slref/matlabfunction.html

STL và thiết kế gốc thuộc repo X-SCARA, công bố theo GPL-3.0. Giữ nguồn và
tuân thủ giấy phép của repo khi phân phối lại thiết kế hoặc dữ liệu mesh.

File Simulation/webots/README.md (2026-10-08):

# Webots: X-SCARA + bút lông

## Mở và chạy

Mở `worlds/scara_draw.wbt` bằng **File → Open World** rồi nhấn **Run**.
Không cần tạo project hay import STL thủ công. Tất cả asset nằm trong `Simulation`
và dùng đường dẫn tương đối; controller Python chỉ dùng thư viện chuẩn.

World dùng định dạng R2025a. Có thể thử trên bản mới hơn bạn cài, nhưng hiện
chưa chạy kiểm chứng bằng Webots thật, kể cả bản 2026. Nguồn phiên bản:
[Cyberbotics releases](https://github.com/cyberbotics/webots/releases).

Nếu Webots không tìm được Python, chọn executable Python 3 trong phần
**Preferences → Python command**, ví dụ
`C:/Users/<tên_user>/AppData/Local/Programs/Python/Python312/python.exe`;
trên máy khác chọn đường dẫn cài Python tương ứng.

Robot có khoảng 2 s đến điểm đầu + 0.5 s ổn định, sau đó vẽ và nhấc bút.
Kết thúc controller giữ vị trí, không tự lặp. Muốn chạy lại hoặc xóa nét,
dùng **Reset/Reload** world. Console hiển thị giai đoạn, sai số XY và lực tì.

## Chọn đường vẽ và thuật toán

Sửa `config/demo.json`, rồi Reset/Reload:

```json
{
  "trajectory": "flower",
  "control_mode": "position",
  "feedforward": true,
  "time_scale": 1.0
}
```

Đây là trích đoạn; giữ các trường khác của file. `trajectory` nhận `flower`,
`circle`, `square`, `csv`. Với `csv`, `csv` là đường dẫn tính từ `Simulation`,
mặc định `common/trajectories/example_drawing.csv`. `time_scale=2` vẽ chậm gấp
đôi. IK kiểm tra toàn bộ quỹ đạo trước khi ra lệnh động cơ.

| Chế độ | Hành vi | File để chỉnh |
| --- | --- | --- |
| position | Gửi góc S/E và vị trí Z qua servo Webots; thích hợp mở lần đầu, kiểm tra IK/quỹ đạo | `core/model.py`, `core/trajectory.py` |
| pid | PID riêng xuất Nm tại hai khớp, N tại Z; setTorque/setForce tắt servo vị trí bên trong Webots | `core/control.py` |
| feedforward | Trong chế độ pid, bật/tắt bù M·qdd + C + ma sát + tiếp xúc ước lượng; trọng lực Z luôn được bù | `core/model.py`, `common/config/scara.json` |

Chế độ position vẫn dùng vật lý/collision. Chế độ pid dùng encoder làm phản hồi,
đạo hàm lọc thấp 30 Hz, bão hòa và anti-windup. Gains được kế thừa từ mô hình
MATLAB; cần thử/tinh chỉnh khi chạy vật lý Webots thật. Mô hình vật lý Webots
và plant giải tích MATLAB khác nhau, nên không kỳ vọng sai số giống hệt.

## Cấu trúc để dễ debug

| File/thư mục | Vai trò |
| --- | --- |
| `worlds/scara_draw.wbt` | Gravity, timestep, camera, bàn, ma sát brush-paper |
| `protos/ScaraBrush.proto` | Cây khớp, motor, encoder, khối lượng/quán tính, boundingObject, bút |
| `protos/DrawingPaper.proto` | Mặt giấy Z=0, UV texture, collision |
| `controllers/scara_draw/scara_draw.py` | Kết nối thiết bị, vòng step, warmup/hold, ghi log |
| `controllers/scara_draw/core/model.py` | FK/IK, crosstalk, feedforward giải tích |
| `controllers/scara_draw/core/trajectory.py` | Hoa/tròn/vuông/CSV, quintic, nội suy tham chiếu |
| `controllers/scara_draw/core/control.py` | PID mô-men/lực và điều kiện cho phép ghi nét |
| `controllers/scara_draw/core/diagnostics.py` | CSV và summary của từng lần chạy |
| `config/demo.json` | Lựa chọn thực nghiệm; không sửa mã để đổi hình/màu/chế độ |
| `tools/build_project.py` | Nguồn tạo world/PROTO/mesh; chỉnh ở đây nếu muốn thay cấu trúc |
| `tools/validate_project.py`, `tests/` | Kiểm thử offline; không cần cài Webots |
| `common/config/scara.json` | Tham số dùng chung với MATLAB; nằm ngoài thư mục webots |

World, PROTO và mesh là file tạo từ builder. Chỉnh trực tiếp PROTO để thử nhanh
được, nhưng tạo lại sẽ ghi đè; nên đưa thay đổi lâu dài vào builder hoặc JSON.
Khi đổi tham số vật lý, chạy `python Simulation/webots/tools/build_project.py`
từ thư mục gốc, rồi Reload world. Controller báo lỗi rõ nếu JSON và world lệch.

## Khớp và thiết bị

```text
SCARA (đế cố định, gốc vai [0,-0.110,0])
└── Z_JOINT / z_motor / z_sensor       Nâng cả carriage + tay + bút
    └── CARRIAGE
        └── SHOULDER_JOINT / shoulder_motor / shoulder_sensor
            └── SHOULDER (L1)
                └── ELBOW_JOINT / elbow_motor / elbow_sensor
                    └── ELBOW (L2)
                        └── BRUSH_BODY
                            └── BRUSH_SPRING / brush_deflection_sensor
                                └── BRUSH_TIP / brush_contact
                                    ├── tool_gps
                                    └── drawing_pen
```

Tọa độ ENU: X/Y nằm trên giấy, Z hướng lên. Encoder quay đo rad, encoder Z đo m.
`brush_contact` là force-3d, `lookupTable []` để đọc N thật thay vì hệ số mặc định
×10. Thành phần |Fz| được ghi là lực tì. GPS nằm ở đáy đầu bút, cho tọa độ thực tế.

Lò xo đầu bút K=800 N/m, C=4 Ns/m, đầu tiếp xúc là cầu bán kính 1 mm với khối lượng
10 g. Phần thân bút 30 g còn lại gắn cứng vào tay. Tổng khối lượng nâng là 1.8 kg.
Webots dùng 2 ms, ma sát brush-paper 0.18. Tất cả là giá trị khởi đầu ước lượng.

Pen hướng -Z, range 0.5 mm. Chỉ bật mực khi quỹ đạo yêu cầu, cảm biến có lực ≥0.02 N,
đầu bút gần mặt giấy và nằm trong giấy 100 × 100 mm. Nét mặc định rộng 0.5 mm.
Pen vẽ vào lớp texture trong phiên mô phỏng; file paper.png vẫn là giấy trắng.

Khớp khuỷu có stop cơ học [-π,π]; giới hạn làm việc 10–170° đặt ở motor và bộ
kiểm tra quỹ đạo. Webots yêu cầu hard stop hinge bao quanh góc zero, vì vậy
không dùng minStop dương. Chế độ raw effort có kiểm tra lệch giới hạn và chuyển
sang giữ vị trí nếu có lỗi. `selfCollision FALSE` và collision đơn giản phù hợp
thử thuật toán, chưa đại diện mọi khoảng hở của cụm lắp STL.

## Log và dùng với MATLAB

Mỗi lần chạy tạo `output/runs/YYYYMMDD_HHMMSS_xxxxxx/`:

- `parameters.json`: chụp lại tham số robot và lựa chọn demo.
- `tracking.csv`: tham chiếu/encoder, XYZ GPS, lực tì, độ nén, trạng thái mực,
  sai số XY, lệnh effort, feedback motor và tọa độ A/B/steps.
- `summary.json`: completed/interrupted/error, RMS/max XY khi yêu cầu vẽ,
  lực lớn nhất. Chỉ có khi controller kết thúc hoặc hoàn tất hình.

Tên cột có đơn vị. Trong position mode, cột `*_command_Nm/N` để trống vì lệnh
là vị trí; feedback vẫn được ghi. Motor feedback không thay thế lực đầu bút.
RMS tính trên mẫu log có pen_requested trong pha draw; không tự loại mẫu mất
tiếp xúc để che sai số. Mặc định log mỗi 5 step = 10 ms.

Trong MATLAB, ở thư mục `Simulation/matlab`:

```matlab
startup_scara
analyze_webots_run % chọn tracking.csv bằng hộp thoại
```

Đây là trao đổi CSV sau chạy; chưa có kết nối thời gian thực MATLAB–Webots hoặc
Simulink đồng mô phỏng.

## Kiểm chứng và xử lý lỗi

```powershell
# Từ Scara Robot
python Simulation/webots/tools/build_project.py
python Simulation/webots/tools/validate_project.py
```

Kết quả: `output/validation/offline_validation.json`. Bộ kiểm tra dùng định nghĩa
trường node từ nguồn Webots R2025a, kiểm tra FK/IK, CSV, PID/anti-windup, I/O
bằng mock, mesh/nguồn/đơn vị, cấu hình và quán tính. Fixture MATLAB đối chiếu
công thức độc lập. Việc này không xác nhận runtime, render hay ODE physics.

`output/validation/geometry_preview.png` là ảnh hình học offline đọc từ PROTO/STL,
có đường vẽ mục tiêu; không là ảnh chụp Webots đang chạy. Có thể tạo lại bằng
`tools/preview_geometry.py` nếu Python có NumPy và Matplotlib; controller và các
kiểm thử chính không cần hai thư viện này.

Khi test thật: mở position mode trước, kiểm tra tay/bút, giấy và Fn trong Console;
sau đó đổi pid, so sánh CSV. Nếu rung, giảm tốc bằng `time_scale=2` trước khi chỉnh
gains/timestep. Nếu có lỗi, xem dòng đầu `[SCARA ERROR]` trong Console.

- Missing device: mở đúng world, giữ nguyên tên device hoặc sửa I/O theo tên mới.
- Physical configuration changed: tạo lại bằng builder, Reload world.
- Không thấy mực: kiểm tra pen_requested/ink_enabled/Fn/Z_tip trong CSV và giấy có texture.
- Rung/mất tiếp xúc: kiểm tra K/C, gain Z, dt và lực khả dụng; chưa hiệu chỉnh trên Webots thật.
- Không tìm được mesh: giữ nguyên cây `Simulation/common` và `Simulation/webots`.

Nguồn: [X-SCARA](https://github.com/madl3x/x-scara),
[Pen](https://cyberbotics.com/doc/reference/pen),
[Motor](https://cyberbotics.com/doc/reference/motor),
[JointParameters](https://cyberbotics.com/doc/reference/jointparameters),
[TouchSensor](https://cyberbotics.com/doc/reference/touchsensor),
[Physics](https://cyberbotics.com/doc/reference/physics).

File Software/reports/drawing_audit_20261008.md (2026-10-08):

# Kiểm tra log nét vẽ

Nguồn: `D:\HK261\Robot\HPMR\Scara Robot\Software\dist\SCARA_Cartesian_NC_v5_R14\logs\cartesian_20261008_104801_16264_86b4eff2.jsonl`

Báo cáo đọc lệnh và telemetry. Không mở COM và không di chuyển robot.

| Mẫu | Cỡ ngang (mm) | Sai lệch mô hình tối đa (mm) | Hoàn tất | Trễ timer tăng lúc vẽ |
|---|---:|---:|---|---:|
| HEART | 46.32 | 0.1398 | Có | 0 |
| CIRCLE | 46.09 | 0.1387 | Có | 0 |
| BK | 46.09 | 0.1511 | Có | 0 |
| LINH | 46.09 | 0.1391 | Có | 0 |
| STAR | 46.09 | 0.1367 | Có | 0 |
| FLOWER | 41.07 | 0.1435 | Có | 0 |

Nét đóng có telemetry xác nhận đúng tọa độ xung cuối: 11/11; xem JSON để đối chiếu từng nét.

Đây không phải phép đo vị trí vật lý. Log không xác nhận motor/bút đã đi đúng các xung đó.

Điểm cần đo tiếp: góc thật của hai đầu hành trình, khoảng cách tâm J1–J2 và tâm J2–đầu bút thực; độ lệch/độ rơ khi đảo chiều và lực tì bút.

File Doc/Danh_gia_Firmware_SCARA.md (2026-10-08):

# Đánh giá firmware SCARA và nguyên nhân nét vẽ bị lệch/cong

> Ngày: 08/10/2026
> Firmware: `SCARA_CART_NC_HOME_V5_R9` (`Firmware/ScaraCartesian`) · GUI: `SCARA_GUI_V5_R13/R14`
> Dữ liệu: toàn bộ mã nguồn firmware, 7 file log phần cứng thật trong
> `Software/dist/SCARA_Cartesian_NC_v5_R14/logs` (6 lần HOME, 58 nét vẽ, 3701 đoạn),
> BOM cơ khí `Hardware/arm/BOM.md`.

---

## Tóm tắt

- Firmware **chạy ổn định** trên phần cứng: HOME lặp lại rất tốt (J1 ±2 xung, J2 ±7 xung), không lần nào cạn bộ đệm hay mất mốc khi đang vẽ, ngắt timer không bị trễ khi vẽ.
- **Nguyên nhân chính khiến hình bị lệch và méo nằm ở bước HOME.** Firmware giả định hai công tắc của mỗi khớp cách nhau đúng 180° rồi suy ra số xung/độ. Log thật cho thấy khoảng cách thật chỉ khoảng **177,5°** ở cả J1 và J2. Thang góc vì vậy sai khoảng 1,4%: đầu bút lệch **0,8–6 mm**, đường tròn méo **0,2–0,9 mm** (tùy phần 2,5° bị thiếu nằm ở đầu nào).
- **Hệ số ghép khuỷu k được đo lại ở mỗi lần HOME** chỉ dựa trên khoảng 64 xung, nên dao động ±1,6%. Hình dịch thêm khoảng 0,4 mm, và mỗi lần HOME dịch một kiểu.
- Cấu hình có **hai giá trị không khớp phần cứng** nhưng đang bị che vì firmware đo lại:
  - Vi bước J1: cấu hình ghi x8, thực tế là 3200 xung/vòng động cơ.
  - k: cấu hình ghi 4/3, thực tế là **1/3** theo cả BOM lẫn log.
- Với nét thẳng ngắn (46 mm), các sai số trên chỉ làm cong dưới 0,07 mm. Nếu nét thẳng **gãy hoặc cong thấy rõ bằng mắt**, hãy nghi **độ rơ** trước (đai, giá bút).
- Đề xuất cho firmware:
  1. Lấy thang góc từ tỷ số truyền; công tắc chỉ dùng làm gốc và để kiểm tra.
  2. Dùng k = 1/3 cố định; phép đo chỉ để bảo vệ.
  3. Bù độ rơ.
  4. Thêm telemetry phục vụ hiệu chuẩn.

  Song song đó cần đo góc thật của công tắc, L1/L2 và vị trí ngòi bút.

---

## 1. Firmware hoạt động thế nào

Phần này tóm tắt những gì cần biết để hiểu các mục sau.

### 1.1 Đường đi của một xung

```
USB CDC (lệnh dạng chữ) ──► main loop (mỗi 2 ms) ──► ct_command() / ct_service()
                                                         │ đặt đích, profile tốc độ
TIM2 1 MHz ──► pulse_tick() (ngắt) ──► đọc 6 công tắc ──► kiểm tra an toàn
                                  └──► DDA chọn trục phát xung ──► chân PUL / DIR
```

- Mỗi xung ứng với **2 lần ngắt**: lần ở cạnh lên phát xung, lần ở cạnh xuống hạ xung. Nếu sang segment mới, DIR được đổi ở cạnh xuống, sau đó còn ít nhất 100 µs trước xung kế tiếp.
- **DDA** (giống Bresenham): trục cần đi nhiều xung nhất ("trục trội") phát một xung mỗi tick, các trục khác phát theo tỷ lệ. Mọi trục bắt đầu và kết thúc cùng lúc, nên giữa hai điểm robot đi **thẳng trong không gian khớp**, không phải thẳng trên giấy.
- GUI tính động học ngược (IK) và chia mỗi nét thành các đoạn khoảng 0,75 mm, rồi gửi `PATH` / `SEG` / `GO`. Firmware **chỉ biết tọa độ động cơ** (số xung).

### 1.2 Các đại lượng quan trọng

| Ký hiệu trong mã | Ý nghĩa |
|---|---|
| `factor` (f) | số xung/độ × 1024 |
| `range` | số xung giữa hai công tắc của một khớp, đo khi HOME |
| `low_md`, `high_md` | góc của hai công tắc **do người dùng nhập** (lệnh `SPAN`, đơn vị mili-độ) |
| `origin` | số xung tại góc 0 |
| `coupling_ppm` (k) | ghép khuỷu: góc khuỷu = B − k·A (đơn vị độ) |
| `beta` (β) | k quy ra xung: β = k·f2/f1 = số xung B cần phát để khuỷu đứng yên khi A đi 1 xung |

**Vì sao có ghép khuỷu (X-SCARA, theo BOM):**
- Tất cả các tầng đều là đai GT2 với puly 20T→60T.
- J1: động cơ A (20T) → puly 60T ở vai, tỷ số 3:1.
- J2: động cơ B (20T) → puly 60T nằm trên trục vai (dính liền với một puly 20T) → puly 60T ở khuỷu, tỷ số 3 × 3 = 9:1.
- Khi B đứng yên mà vai quay A độ: puly 20T trên trục vai đứng yên so với đế, nên khuỷu quay tương đối −A·20/60 = **−A/3**. Vậy k = 1/3.

### 1.3 Trình tự HOME (rút gọn)

1. **Z**: quét hai biên, kết thúc ở biên trên.
2. **J2_PRE**: quét hai biên J2 (hai lần đo n1 và n2 phải lệch nhau ≤ 1%), rồi về giữa.
3. **Dò ghép**: J1 đi 128 xung, quét lại một biên J2, đo β = ΔB/ΔA.
4. **J1**: quét hai biên J1; J2 chạy bù theo β để khuỷu không đụng biên.
5. J1 về góc đỗ, **J2_FINAL**: quét J2 lần nữa để lấy gốc J2.
6. **Đỗ**: Z lùi cách biên trên 3 mm.

Thang góc được tính ở [cart_core.c](../Firmware/ScaraCartesian/src/cart_core.c), dòng 371–374:

```
factor = range / (high_md − low_md)    // ví dụ: 4733 xung / 180° = 26,29 xung/°
origin = vị trí công tắc thấp − low_md × factor
```

→ **Thang góc phụ thuộc hoàn toàn vào góc công tắc do người dùng nhập (±90°).** Cách này có từ R7: nó giúp robot không đâm biên khi cấu hình vi bước sai. Đổi lại, độ chính xác phụ thuộc vào một con số chưa ai đo.

---

## 2. Đã kiểm tra những gì

| Hạng mục | Cách làm | Kết quả |
|---|---|---|
| Mã nguồn | Đọc toàn bộ `src/`, `app.overlay`, `prj.conf` | Mục 8 |
| Test có sẵn | Build bằng gcc (MSYS2) như `tools/verify.ps1`, chạy `test_cart_core` và `test_motor_io` | Pass cả hai |
| Hành vi PATH/MOVE | Viết test riêng chạy trên lõi `cart_core.c` | Mục 8 |
| Log phần cứng thật | Trích 7 file log ngày 07–08/10 | Mục 3 |
| Cơ khí | Đối chiếu `Hardware/arm/BOM.md` | Tỷ số 3:1 và 9:1, k = 1/3 |
| Ảnh hưởng của từng sai số | Mô phỏng động học L1 = L2 = 98 mm tại đúng vị trí vẽ trong log | Mục 4 |

---

## 3. Kết quả từ log phần cứng thật

### 3.1 Sáu lần HOME

| Phiên | range Z | range J1 | range J2 | ΔB khi dò (xung) | k firmware tính |
|---|---:|---:|---:|---:|---:|
| 07/10 17:41 | 87419 | 4732 | 7104 | 64 | 0,3331 |
| 07/10 18:47 | 87364 | 4732 | 7102 | 64 | 0,3331 |
| 07/10 20:07 | 87360 | 4732 | 7107 | 64 | 0,3329 |
| 07/10 20:41 | 87365 | 4735 | 7103 | 65 | 0,3385 |
| 08/10 10:48 | 87277 | 4733 | 7094 | 65 | 0,3388 |
| 08/10 13:06 | 87230 | 4733 | 7106 | 63 | 0,3278 |

### 3.2 Diễn giải

1. **Công tắc và HOME lặp lại rất tốt.** J1 đo được 4732–4735 xung, J2 7094–7107. Trong cùng một lần HOME, n1 và n2 lệch nhau ≤ 1 xung. Không có dấu hiệu mất bước khi quét.
2. **Vi bước J1 trong cấu hình không khớp phần cứng.**
   - GUI gửi `GEOM … 13653 …`, tức 13,33 xung/° (x8, 3:1).
   - Đo được 4733 xung cho "180°", tức 26,3 xung/°, gần gấp đôi.
   - Tỷ số J1 là 3:1 cố định theo BOM, nên driver J1 thực tế đang chạy **3200 xung/vòng động cơ**: hoặc DIP x16 với động cơ 1,8°, hoặc x8 với động cơ 0,9°. **Cần kiểm tra lại.**
3. **Hai công tắc của mỗi khớp chỉ cách nhau khoảng 177,5°**, không phải 180°:
   - J1: 4733 / 26,667 = **177,5°**
   - J2: 7104 / 40 = **177,6°**

   Cả hai khớp đều thiếu khoảng 2,5°. Nguyên nhân có thể là cần gạt công tắc tác động sớm, hoặc công tắc không được lắp đúng ±90°. Chỉ đo trực tiếp trên robot mới biết phần thiếu nằm ở đầu nào.
4. **k thật = 1/3.** BOM và log khớp nhau: β danh định = (1/3) · 40 / 26,667 = 0,5, và ba trong sáu lần đo cho đúng 64/128 = 0,5. Cấu hình đang ghi 1,333333 nhưng không gây hại, vì firmware đo lại và GUI dùng giá trị đo.
5. **Phép dò ghép quá ngắn.** 128 xung J1 chỉ cho khoảng 64 xung J2, nên sai 1 xung đã là 1,6%. Vì vậy k dao động 0,328–0,339 giữa các lần HOME.
6. **Khi vẽ, phần phát xung không có vấn đề.**
   - 58 nét gồm 3701 đoạn; mỗi đoạn trung vị 17 xung; tốc độ đỉnh trung vị 213 xung/s, lớn nhất 276 xung/s.
   - Không lần nào cạn bộ đệm.
   - `timer_late` chỉ tăng 0–1 lần trong toàn bộ thời gian vẽ.
   - Sai lệch do GUI chia đoạn và làm tròn xung ≤ 0,14 mm.
7. **`timer_late` = 266 ở phiên chạy R9.** Toàn bộ 266 lần đều xảy ra ở bước HOME trục Z, chạy 4800 xung/s (chu kỳ 208 µs). Các xung này bị trễ chứ không mất, nên Z vẫn lặp lại tốt. Tuy vậy đây là dấu hiệu ngắt bị khóa quá lâu (mục 8, dòng 4).
8. **Mỗi lần kết nối có đúng một dòng JSON bị cắt**, ghi nhận là `rx_rejected` ở giây 0,2. Firmware gửi status liên tục cả khi GUI chưa mở cổng; bộ đệm USB đầy thì byte bị bỏ. GUI loại dòng hỏng nên không gây hại, nhưng nó xác nhận vấn đề chưa kiểm tra DTR (mục 8, dòng 5).
9. **Không có lệnh STOP nào cắt ngang lúc robot đang chạy.** Có 20 lệnh STOP (USER 5, FOCUS 8, DISCONNECT 6, CLOSE 1), tất cả gửi lúc robot đứng yên. Không có lệnh nào bị từ chối, và robot chưa lần nào mất mốc khi đang chạy.

---

## 4. Vì sao nét vẽ bị lệch và cong

### 4.1 Cơ chế

Firmware tin rằng công tắc nằm ở ±90°. Nếu thực tế chúng chỉ cách nhau 177,5°, thì mỗi "độ" firmware tính ra chỉ bằng 0,986° thật.

Ví dụ tại tâm vùng vẽ trong log (x = 0, y = 165 mm), IK cho góc vai −32,67° và góc khuỷu 65,33°:

| Giả thiết về công tắc | Góc thật (vai, khuỷu) | Đầu bút lệch |
|---|---|---|
| Thiếu đều hai đầu (công tắc ở ±88,75°) | −32,21°, 64,46° | 0,8 mm |
| Thiếu hết ở đầu cao (công tắc thấp đúng −90°) | −33,48°, 63,26° | 5,7 mm |

Sai số góc thay đổi theo tư thế, nên sai số đầu bút cũng thay đổi theo vị trí. Kết quả là hình **vừa bị dời chỗ, vừa bị méo**.

### 4.2 Bảng độ nhạy

Điều kiện mô phỏng:
- L1 = L2 = 98 mm, hình 46 mm đặt tại tâm (0, 165) giống log.
- Lệnh khớp được tính bằng IK lý tưởng; robot "thật" chỉ mang đúng một sai số trong mỗi trường hợp.

| Nguồn sai số | Nét tiếp tuyến cong | Nét hướng kính cong | Tròn méo (Rmax − Rmin) | Lệch vị trí lớn nhất |
|---|---:|---:|---:|---:|
| Khoảng 177,5° bị coi là 180°, thiếu đều hai đầu | 0,00 mm | 0,01 mm | 0,38 mm | 1,4 mm |
| như trên, thiếu hết ở đầu cao | 0,04 mm | 0,01 mm | 0,94 mm | 6,3 mm |
| như trên, thiếu hết ở đầu thấp | 0,03 mm | 0,01 mm | 0,24 mm | 6,3 mm |
| k dao động theo lần HOME (±1 xung) | 0,02 mm | 0,04 mm | 0,23 mm | 0,4 mm |
| Độ rơ J1 0,3° | 0 | 0 | 0,67 mm | 0,5 mm |
| Độ rơ J2 0,3° | **0,27 mm** (gãy giữa nét) | 0 | 0,44 mm | 0,3 mm |
| Gốc 0 của J1 lệch 1° | 0 | 0 | 0 | 3,3 mm (cả hình xoay) |
| Gốc 0 của J2 lệch 1° | 0,03 mm | 0 | 0,47 mm | 1,7 mm |
| L1 (hoặc L2) thật là 99 mm thay vì 98 | 0,00 mm | 0,06 mm | 0,27 mm | 1,0 mm |

Độ phân giải không phải nguyên nhân:
- 1 xung J1 = 0,0375°, tức 0,11 mm ở bán kính 165 mm.
- 1 xung J2 = 0,025°, tức 0,04 mm.

### 4.3 Cách đọc bảng

- **Cả hình bị dời chỗ:** chủ yếu do thang góc và gốc 0 của khớp, cỡ vài mm.
- **Đường tròn bị méo:** nhạy nhất với thang góc, gốc 0 của khuỷu, chiều dài khâu và độ rơ. Mỗi nguồn gây 0,2–0,9 mm; cộng dồn có thể lên 1–2 mm.
- **Nét thẳng ngắn:** các sai số tham số chỉ làm nét 46 mm cong dưới 0,07 mm. Độ cong tăng theo bình phương chiều dài, nên nét 90 mm cong khoảng gấp 4 lần.
  - Nếu nét 46 mm cong hoặc gãy thấy rõ bằng mắt, hãy nghi **độ rơ** trước. Khi vẽ nét tiếp tuyến, khuỷu đổi chiều ngay giữa nét.
  - Cũng cần kiểm tra **giá bút bị rơ** hoặc **cánh tay bị võng**.
- **Hai sai số chỉ làm hình to/nhỏ hoặc xoay, không làm méo:**
  - Gốc 0 của J1 lệch: cả hình xoay quanh trục vai.
  - L1 và L2 cùng sai một tỷ lệ: hình phóng to hoặc thu nhỏ.

---

## 5. Đề xuất sửa firmware

### Bước 0: sửa cấu hình cho khớp phần cứng (làm trước)

- Kiểm tra DIP vi bước của driver J1, và động cơ J1 là loại 1,8° hay 0,9°. Nếu là 3200 xung/vòng với động cơ 1,8° thì đặt `microsteps` = `[16, 16, 8]`.
- Đặt `coupling` = `0.333333`.

Hiện tại hai giá trị sai này không gây hại vì firmware đo lại. Nhưng mọi phép kiểm tra "so với danh định" ở dưới đều cần chúng đúng.

### Đề xuất 1: thang góc lấy từ tỷ số truyền, công tắc chỉ dùng làm gốc và để kiểm tra

Thay đoạn ở `cart_core.c`, dòng 369–374:

```c
unsigned a = c->selected;
c->range[a] = c->cal[a].pulses;
uint64_t f = c->nominal[a];                       /* vi bước × tỷ số răng: chính xác */
if (a == CT_Z && c->z_span_um)                    /* Z giữ như cũ */
    f = (uint64_t)c->range[a] * 1024000 / c->z_span_um;
if (a != CT_Z) {
    unsigned j = a - 1;
    int32_t typed = c->high_md[j] - c->low_md[j];
    int32_t span  = (int32_t)((uint64_t)c->range[a] * 1024000U / f);   /* m° thật */
    if (abs(span - typed) > typed / 20)           /* lệch > 5%: sai DIP / tỷ số */
        return init_fail(c, "scale_mismatch");
    c->span_md[j] = span;                         /* trường mới, đưa vào status */
    c->high_md[j] = c->low_md[j] + span;          /* giới hạn mềm theo công tắc thật */
}
c->factor[a] = (uint32_t)f;
```

Kết quả:
- **Thang góc đúng tuyệt đối.** Sai số do làm tròn ×1024 dưới 0,002%.
- **Sai DIP hoặc sai tỷ số bị phát hiện:** HOME dừng với `scale_mismatch`, thay vì âm thầm bỏ qua như J1 hiện nay.
- **Giá trị thấp trong `SPAN` trở thành góc thật của công tắc thấp**, cần đo (mục 6). Giá trị cao chỉ còn dùng để kiểm tra.
- **GUI không cần đổi IK** vì vẫn đọc `factor`. Tuy vậy GUI nên đọc `span_md` để đặt giới hạn khớp khớp với công tắc thật.

### Đề xuất 2: k cố định theo cơ khí, phép dò chỉ để bảo vệ

Ở bước `HS_COUPLE_SCAN` (`cart_core.c`, khoảng dòng 420–436), sau khi đã tính `measured`:

```c
int64_t nominal = rounded((int64_t)c->coupling_ppm * c->nominal[2] * CT_Q,
                          (int64_t)1000000 * c->nominal[1]);   /* β = k·f2/f1 */
c->beta_measured = measured;                                   /* trường mới, cho telemetry */
if (llabs(measured - nominal) > llabs(nominal) / 20)           /* lệch > 5% */
    return init_fail(c, "coupling_mismatch");
c->beta = nominal;                                             /* dùng hằng số cơ khí */
c->coupling_ready = true;
```

Đồng thời bỏ khối tính lại `coupling_ppm` từ phép dò ở dòng 375–380, để k giữ đúng giá trị cấu hình.

- **Vẫn giữ phép dò**, vì nó bảo vệ robot trước lượt quét J1 dài; đây là lý do R7 thêm nó vào. Nếu cấu hình sai thì β đo được sẽ lệch xa danh định, và HOME dừng trước khi J2 đâm biên.
- **Hiệu quả:** k không còn dao động theo từng lần HOME, nên mất đi khoảng 0,4 mm dịch hình ngẫu nhiên.
- **Nếu vẫn muốn đo k:** tính β từ hai lần quét J2 sẵn có (`HS_J2_PRE` và `HS_J2_FINAL`). Quãng J1 giữa hai lần này thường dài hàng nghìn xung, so với 128 xung hiện nay, nên chính xác hơn hàng chục lần. Nếu robot khởi động sát tư thế đỗ thì hai vị trí quá gần nhau; khi đó thêm một lần quét J2 tại J1 = tư thế đỗ ± 45°.

### Đề xuất 3: bù độ rơ (làm sau khi đo được độ rơ)

Thêm lệnh `BACKLASH <session> <xung A> <xung B>`. Firmware nhớ chiều quay gần nhất của từng động cơ. Khi một segment làm động cơ đó đổi chiều, firmware phát thêm N xung bù trước, **không cộng vào `pos`**:

```c
/* trạng thái mới */
uint16_t backlash[CT_AXES], comp_left[CT_AXES]; int last_dir[CT_AXES];

/* khi nạp đoạn mới (raw_move / ct_path_advance) */
for (unsigned a = CT_J1; a <= CT_J2; a++) {
    if (c->direction[a] && c->last_dir[a] && c->direction[a] != c->last_dir[a])
        c->comp_left[a] = c->backlash[a];
    if (c->direction[a]) c->last_dir[a] = c->direction[a];
}
/* pulse_tick(), cạnh lên: nếu còn comp_left thì chỉ phát xung bù
 * ở tốc độ thấp cố định (ví dụ 200 xung/s), KHÔNG gọi ct_count(),
 * xong mới chạy DDA của đoạn. */
```

- **Ở khuỷu, xét chiều của động cơ B** chứ không phải chiều góc khuỷu, vì độ rơ nằm trong truyền động của B.
- **Trong PATH, khớp thường đổi chiều đúng lúc vận tốc khớp gần bằng 0**, nên chèn vài xung chỉ gây khựng rất ngắn.
- **Sau HOME phải ghi nhận lại chiều quay**, vì đó là chiều của lần đi vào tư thế đỗ.

### Đề xuất 4: telemetry phục vụ hiệu chuẩn

Báo thêm trong status:
- `span_md`: góc thật giữa hai công tắc của mỗi khớp.
- `beta_measured` và `beta_nominal`.
- Số xung bù độ rơ đã phát.

Nhờ đó mỗi lần HOME tự để lại số liệu kiểm tra trong log.

---

## 6. Hiệu chuẩn hình học (ngoài firmware nhưng cần làm)

Firmware không thể tự biết ba thứ: **góc thật của công tắc**, **L1/L2 thật**, và **vị trí ngòi bút** (`tool_offset_mm` hiện đang là (0, 0)).

1. **Góc công tắc.**
   - Nhả J1/J2 bằng lệnh `HOLD … 0`, đẩy tay cho tới khi công tắc kêu.
   - Đo góc so với trục Y của robot bằng thước đo góc. Cách tiện hơn: in một tờ giấy có các vạch góc với tâm đặt tại trục vai, dán dưới robot.
   - Nhập kết quả vào `joint_limits_deg` thay cho ±90.
2. **L1, L2 và ngòi bút.**
   - Dùng thước kẹp đo từ tâm trục vai tới tâm trục khuỷu, và từ tâm khuỷu tới tâm ngòi bút.
   - Nếu ngòi bút không nằm trên đường tâm khâu 2, nhập độ lệch vào `tool_offset_mm`.
3. **Kiểm tra bằng hình vẽ.**
   - Vẽ một hình vuông 60 mm có hai đường chéo, rồi đo 4 cạnh và 2 đường chéo bằng thước kẹp.
   - Cạnh sai tỷ lệ là do L1/L2 hoặc thang góc. Hai đường chéo dài khác nhau nghĩa là hình bị méo (gốc khuỷu, thang góc).
   - Sáu số đo này đủ để GUI tìm (bằng bình phương tối thiểu) gốc khuỷu, L1, L2 và thang góc.
   - Gốc 0 của J1 chỉ làm hình xoay, không làm méo, nên chỉ cần khi muốn đặt hình đúng vị trí tuyệt đối trên giấy.

---

## 7. Bài vẽ thử để chẩn đoán (làm trước khi sửa)

| # | Cách làm | Nếu thấy | Nghĩa là |
|---|---|---|---|
| 1 | Vẽ cùng một đường tròn D46 ở 3 vị trí (gần đế, giữa, xa đế) | Độ méo thay đổi theo vị trí | Lỗi tham số hình học → đề xuất 1, mục 6 |
| | | Có 4 bậc nhỏ ở những chỗ giống nhau | Độ rơ → đề xuất 3 |
| 2 | Vẽ một đoạn thẳng 40 mm đi rồi vẽ về | Hai nét không trùng nhau | Khoảng cách giữa hai nét xấp xỉ độ rơ |
| 3 | HOME 2 lần, mỗi lần chấm cùng một dấu + | Hai dấu lệch nhau 0,3–0,5 mm | k dao động → đề xuất 2 |
| 4 | Vẽ hình vuông có đường chéo rồi đo | Xem mục 6 | |
| 5 | Lắc nhẹ giá bút khi bút đang chạm giấy | Có rơ | Cần sửa cơ khí giá bút |

---

## 8. Các vấn đề khác của firmware (đánh giá lại sau khi có log)

| # | Vấn đề | Bằng chứng | Mức độ | Hướng sửa |
|---|---|---|---|---|
| 1 | Không có E-stop phần cứng, không giám sát nguồn động cơ. Mất 24 V khi đang chạy thì firmware vẫn đếm xung và vẫn báo có mốc | Overlay không có chân nào cho việc này | Cao (an toàn) | Mạch E-stop NC cắt nguồn driver, cộng một GPIO báo MCU; cầu phân áp đo VMOT |
| 2 | Điều khiển vòng hở, không phát hiện mất bước | Do thiết kế | Trung bình (log chưa thấy mất bước) | Lệnh "verify home": đi về công tắc và so số xung; hoặc gắn AS5600 ở khớp (phụ lục A) |
| 3 | Thang góc và k không được đối chiếu với giá trị danh định | Mục 3 | **Cao đối với độ chính xác** | Đề xuất 1–2 |
| 4 | `command()` phân tích lệnh và định dạng chuỗi (`sscanf`, `snprintf`) ngay trong vùng khóa ngắt, kể cả với lệnh KEEP | `timer_late` = 266 khi HOME Z ở 4800 xung/s | Thấp–trung bình | Trong vùng khóa chỉ chép trạng thái; định dạng chuỗi ở ngoài |
| 5 | Status vẫn gửi khi GUI chưa mở cổng; console dùng chung cổng với giao thức | Một dòng JSON hỏng mỗi lần kết nối | Thấp | Kiểm tra DTR bằng `uart_line_ctrl_get`; tắt `CONFIG_UART_CONSOLE` hoặc dùng CDC riêng |
| 6 | Lệnh bị từ chối trong lúc đang chạy làm robot dừng và mất mốc | Test riêng: gửi MOVE khi đang chạy thì robot abort | Thấp (chưa xảy ra trong log) | Từ chối lệnh vô hại mà không abort |
| 7 | STOP và mất heartbeat (350 ms) đều dừng tức thì và luôn làm mất mốc | Do thiết kế | Thấp–trung bình | Dừng có giảm tốc; giữ mốc khi người dùng bấm STOP |
| 8 | Một giới hạn tốc độ chung 1600 xung/s cho mọi trục | Z chỉ đạt 1 mm/s, nên mỗi lần nhấc bút 2 mm mất khoảng 2 s | Trung bình (thời gian vẽ) | Giới hạn tốc độ riêng cho từng trục (Z có thể tới 6400 xung/s như lúc HOME) |
| 9 | PATH không kiểm tra bước nhảy vận tốc của từng trục tại điểm nối | Test riêng: firmware chấp nhận J1 nhảy 250→1000 xung/s, và J2 đảo chiều ở 1000 xung/s | Thấp (GUI đã lập profile tốt; tốc độ ≤ 276 xung/s) | Lớp bảo vệ cuối: giới hạn Δv của từng trục |
| 10 | Không có watchdog phần cứng (IWDG) | `prj.conf` | Thấp | Bật `CONFIG_WATCHDOG`, nạp watchdog trong main loop |
| 11 | Giả định ngầm: hai công tắc của một trục phải cùng port; TIM2 16-bit chỉ đếm tới khoảng 65 ms | `main.c` dòng 36, `app.overlay` | Thấp | Thêm `BUILD_ASSERT` |
| 12 | `main()` gặp lỗi khởi tạo thì chỉ `return 0`, không báo gì | `main.c` dòng 296–305 | Thấp | Đưa về trạng thái an toàn và nháy LED báo mã lỗi |
| 13 | Mã khó đọc; còn mã chết (`zj_command`, `zj_period_us`, `zj_reason_name`); nhiều số ma thuật | | Thấp | Dùng enum và hằng số có tên, xóa mã chết |
| 14 | Flash đã dùng 83%, RAM 87% | `verification_nc_v5_R9.json` | Lưu ý | Cân nhắc STM32F401/F411 nếu thêm tính năng |
| 15 | Không dùng git | | Quy trình | `git init`, đánh tag theo số R |

### Đính chính so với nhận xét trước

- Cờ `"real_hardware_tested": false` trong `verification_nc_v5_R9.json` là thông tin cũ. Log cho thấy firmware đã chạy thật nhiều giờ.
- Trước đây mình đề xuất bắt buộc `entry[k] == exit[k-1]` cho SEG. Điều đó **sai**: GUI cố ý giữ vận tốc **đầu bút** liên tục, nên tốc độ tick giữa hai đoạn khác nhau là đúng. Phép kiểm tra đúng phải là bước nhảy vận tốc **của từng trục** (dòng 9 ở bảng trên).

---

## 9. Thứ tự đề nghị

1. Kiểm tra DIP và loại động cơ J1; sửa cấu hình (`microsteps`, `coupling`).
2. Làm bài thử 1–3 (mục 7) để biết độ rơ lớn hay nhỏ.
3. Làm đề xuất 1 và 2, đo góc công tắc thật, rồi vẽ lại để so sánh.
4. Hiệu chuẩn L1, L2 và ngòi bút (mục 6).
5. Nếu bài thử 2 cho thấy độ rơ lớn hơn khoảng 0,1°, làm đề xuất 3.
6. Các mục an toàn và độ bền ở mục 8 (E-stop, VMOT, DTR, khóa ngắt).

---

## Phụ lục A: Gắn AS5600 để đo góc khớp

**Vị trí gắn:**
- Nên gắn trên **trục khớp**, không gắn ở đuôi động cơ.
  - J1: nam châm ở đầu trục puly 60T của vai, cảm biến bắt vào đế.
  - J2: nam châm ở trục khuỷu, cảm biến bắt trên khâu 1. Cảm biến này đo trực tiếp **góc khuỷu tương đối**, đúng đại lượng IK dùng, nên kiểm tra được cả k.
- Gắn ở khớp còn có lợi thế phát hiện được trượt đai và độ rơ, và biết ngay góc tuyệt đối khi bật nguồn (vì khớp chỉ quay khoảng ±90°).

**Độ phân giải:** 4096 điểm/vòng, tức 0,088°/điểm.
- J1: 1 bước đầy tương ứng 0,6° ở khớp, khoảng 7 điểm.
- J2: 1 bước đầy tương ứng 0,2° ở khớp, khoảng 2 điểm.
- Khi động cơ bước mất đồng bộ, nó thường trượt theo bội của 4 bước đầy, nên phát hiện được dễ dàng.

**Lắp cơ khí:**
- Nam châm Ø6×2,5 mm, **từ hóa ngang** (diametric). Loại từ hóa dọc trục không dùng được.
- Dán bằng epoxy, đặt đúng tâm trục.
- Khe hở giữa nam châm và chip 0,5–3 mm.
- Gá bằng nhựa hoặc nhôm; tránh ốc và vòng đệm thép ở gần cảm biến.
- Kiểm tra bằng thanh ghi `STATUS` (0x0B): MD = 1 là có nam châm, ML là quá xa, MH là quá gần. Thanh ghi `AGC` (0x1A) nên nằm khoảng giữa dải.

**Đấu dây:**
- **Chân DIR phải nối cứng** xuống GND hoặc lên VCC, không để hở.
- **Khi chạy 3,3 V phải nối VDD5V với VDD3V3.**
- **Địa chỉ I²C cố định 0x36**, nên hai cảm biến sẽ trùng địa chỉ. Dùng mux TCA9548A, hoặc dùng AS5600L (đổi được địa chỉ).
- **Dùng I2C1 ở PB6/PB7** (đang trống); PB10/PB11 đã dành cho công tắc J2.
- **Dây tới khuỷu dài:** chạy 100 kHz, pull-up ngoài 2,2 kΩ, dây xoắn đôi (SDA với GND, SCL với GND), đi xa dây pha động cơ.

**Firmware:**
- Đọc thanh ghi RAW ANGLE (0x0C–0x0D) trong một thread riêng ở 100–200 Hz. Không đọc I²C trong ngắt hay trong `irq_lock`.
- So góc đo được với góc tính từ `pos`. Nếu lệch quá khoảng 2–4 bước đầy trong vài lần đọc liên tiếp, dừng robot và hủy mốc HOME.

---

## Phụ lục B: Tự kiểm tra lại từ log

Chạy từ thư mục gốc dự án. Đoạn mã in ra góc thật giữa hai công tắc và k của mỗi lần HOME:

```python
import json, glob

J1_PULSES_PER_DEG = 3200 * 3 / 360   # sửa nếu DIP/động cơ J1 khác
J2_PULSES_PER_DEG = 1600 * 9 / 360

for f in sorted(glob.glob('Software/dist/SCARA_Cartesian_NC_v5_R14/logs/cartesian_*.jsonl')):
    seen = set()
    for line in open(f, encoding='utf-8'):
        if '"referenced":1' not in line:
            continue
        s = json.loads(line).get('status')
        if not s or not s['referenced'] or s['epoch'] in seen:
            continue
        seen.add(s['epoch'])
        r = s['range']
        print(f[-45:], f"J1 {r[1] / J1_PULSES_PER_DEG:.2f}°  J2 {r[2] / J2_PULSES_PER_DEG:.2f}°",
              f"k={s['coupling_ppm'] / 1e6:.4f}  dò={s['probe_da']}/{s['probe_db']}")
```

Sau khi làm đề xuất 1–2, góc in ra phải ổn định, còn k phải đúng bằng 0,3333 ở mọi lần HOME.

---

## Phụ lục C: Giả định của mô phỏng (mục 4)

- Mô hình hai khâu phẳng, L1 = L2 = 98 mm, không có độ lệch ngòi bút. Tâm hình (0, 165) theo khung tọa độ của GUI, là vị trí được dùng trong log.
- Hình mẫu gồm: nét thẳng 46 mm theo hướng tiếp tuyến và theo hướng kính, và đường tròn D46. "Cong" là độ lệch lớn nhất so với đường thẳng khớp nhất; "méo tròn" là Rmax − Rmin so với đường tròn khớp nhất.
- Mỗi trường hợp chỉ có một nguồn sai số. Trên robot thật các sai số cộng dồn với nhau.
- Độ rơ được mô hình hóa đơn giản: khớp trễ b/2 theo chiều đang chuyển động.
- Sai thang góc được mô phỏng là phép co giãn quanh công tắc thấp, công tắc cao, hoặc đối xứng, tùy giả thiết.

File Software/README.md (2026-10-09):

# SCARA — GUI R14 / firmware R9

Chỉ giữ bộ hiện tại. Mở **Run_Cartesian_GUI.bat**; EXE nằm trong
`dist/SCARA_Cartesian_NC_v5_R14/`. Firmware tương ứng:
`../Firmware/ScaraCartesian/Hex/SCARA_Cartesian_NC_Home_v5_R9.hex`, nạp tại
`0x08000000`. Dòng firmware trong GUI phải là `SCARA_CART_NC_HOME_V5_R9`.

## Dùng robot

1. Kết nối COM, kiểm tra **Cơ khí**, rồi **HOME / CALIB**.
2. Điều khiển bằng XYZ hoặc tab **Chỉnh mô hình**; chuỗi điểm có trong
   **Điểm thử / Chuỗi setpoint**. Tọa độ là ước tính từ xung, chưa có encoder.
3. **Thư viện hình & chữ** có BK/LINH/THOA, hoa6 cánh, sao, trái tim,
   tròn, elip, vuông, tam giác, hình thoi. Chọn cỡ/tâm hoặc phóng vừa vùng.
4. Chỉnh bút vừa chạm giấy, lấy/xác nhận Z giấy; chạy khô trước khi vẽ.
   Các nét dùng chuyển động liên tục, nâng bút khi đổi nét và khi hoàn thành.
5. Dừng/Esc, mất USB/heartbeat/status, lỗi biên/GPIO, reset hoặc nhả arm
   đang dùng làm mất mốc. Khi đó HOME lại. Chuyển app giữ chạy nền theo
   cấu hình; chế độ bám chuột tắt bám và hoàn thành đoạn ngắn đã gửi.

## Cơ khí và độ chính xác

Mặc định L1/L2=98mm, hai khớp có góc công tắc±90°, Zlead2mm/vòng, vi bước
Z16/J1–J2 8. Phải đo kích thước tới đầu bút và góc thực tại công tắc.
Calib đo số xung giữa biên và đo bù dB/dA; không tự biết góc thực hoặc vị trí
bút. Z calib3mm/s theo lead cấu hình, chốt400pps; Z thường1mm/s.

`tool_offset_mm=[x,y]`: lệch ngang phải và dọc theo arm2, tính từ điểm
chuẩn cuối L2 đến đầu bút. Khi hai arm thẳng theo+Y, các hướng này là+X/+Y.
Mặc định `[0,0]`; chưa đo thì giữ nguyên. Không cộng cùng độ lệch vào cảL2
và offset. FK/IK/vùng với tới dùng cùng thông số. Lưu thay đổi rồi HOME lại.

Bộ đếm đúng không chứng minh motor/bút đã đến vị trí vật lý. Với nét méo,
so cùng mẫu ở4mm/s và12mm/s, tì bút nhẹ, giữ chắc gá/giấy, kiểm tra độ rơ
và các khoảng cách/góc đã đo. Báo cáo log thật: [báo cáo](reports/drawing_audit_20261008.md).

## Cấu trúc

- `src/`: mã GUI, mô hình, giao tiếp, hình vẽ, log và phân tích.
- `tests/`: kiểm thử hiện tại, chỉ dùng cổng giả lập.
- `packaging/`: một spec PyInstaller cho GUI R14.
- `dist/SCARA_Cartesian_NC_v5_R14/`: bộ chạy; **giữ nguyên `_internal`**.
  Cấu hình và log phiên nằm cạnh EXE; log cũ có ích đã được gom vào `logs/`
  tại đây. Dữ liệu phiên mô phỏng và các bản phát hành cũ đã được bỏ.
- `reports/`: báo cáo kiểm thử hiện tại và kiểm tra nét vẽ.

## Phát triển và kiểm thử

Python3.12, `pip install -r requirements.txt`. Chạy nguồn:
`python src/cartesian_nc_control.py`; `--demo` không mở COM thật.
Build EXE: `./Build_Cartesian_NC_GUI.ps1`. Script cài bộ đóng gói theo
`requirements-build.txt` vào `.packaging/` nếu chưa có. Đây là cache có thể xóa.

Kiểm thử: `./Verify_Cartesian_NC_GUI.ps1 -Gui`. Script luôn build/kiểm thử
harness firmware trước để tránh dùng mẫu C cũ, rồi tự tìm mọi `test_*.py`.
Từ thư mục gốc, có thể chạy `./Verify_SCARA.ps1 -Gui`. Bỏ `-Gui` để chỉ chạy
các unit; `-Python` và `-Gcc` nhận đường dẫn công cụ nếu chưa có trên PATH.
Build/checks tạo `build/`, `__pycache__/`, `Firmware/ScaraCartesian/build_host/`;
đó là sản phẩm sinh lại, có thể xóa sau khi dùng. Các kiểm thử không chạy robot.

GUI được chia theo trách nhiệm: `cartesian_nc_control.py` khởi tạo và điều phối
vòng Tk; `cartesian_nc_connection.py` xử lý USB/session/ACK/status;
`cartesian_nc_motion.py` quản lý lệnh, chuỗi điểm và upload nét;
`cartesian_nc_planning.py` quản lý worker tính đường đi và loại kết quả khi mốc
hoặc vị trí đã đổi; `cartesian_nc_safety.py` quản lý STOP/focus;
`cartesian_nc_view.py` dựng dashboard/cài đặt. Timing và điều kiện cho phép chạy
nằm trong `cartesian_nc_policy.py`, màu/thông báo trong các module riêng.
`NCApp`, CLI, cấu hình JSON và giao thức firmware vẫn giữ giao diện hiện tại.

Định dạng Python bằng Black 26.1.0 (`pip install -r requirements-dev.txt`, rồi
`python -m black src tests packaging/SCARA_Cartesian_NC_v5_R14.spec`).

Phân tích log chỉ đọc, không mở COM:
`python src/cartesian_nc_audit.py path/to/session.jsonl --out reports/drawing_audit`.
Log `stroke_start`, `stroke_complete`, `drawing_complete` lưu profile, xung,
thời gian và lỗi bộ đệm. Báo cáo không đo được trượt bước, độ rơ hoặc bút võng.

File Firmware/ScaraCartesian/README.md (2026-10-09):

# SCARA Cartesian — firmware R9

Nguồn Zephyr3.7 cho Blue Pill STM32F103C8 (64KiB flash,20KiB RAM).
Bộ hiện tại: `Hex/SCARA_Cartesian_NC_Home_v5_R9.hex` và `.bin`.
Nạp tại `0x08000000`, reset. Build tag `SCARA_CART_NC_HOME_V5_R9`, protocol5.
GUI hiện tại ở `../../Software/Run_Cartesian_GUI.bat`.

## Đấu dây

TB6600 kiểu chung âm: PUL−, DIR−, ENA− nối GND chung.

| Trục | PUL+ | DIR+ | ENA+ | Biên DIR HIGH | Biên DIR LOW |
|---|---|---|---|---|---|
| Z | PA0 | PA1 | PA2 | PA3 trên | PA4 dưới |
| J1 | PA8 | PB15 | PB14 | PB0 | PB1 |
| J2 | PA6 | PA7 | PB13 | PB10 | PB11 |

Công tắc **COM–NC**: COM→GND, NC→GPIO kéo lên3,3V; NO bỏ trống.
Bình thường LOW, chạm/hở dây HIGH. J2 DIR HIGH quay ngược dấu hình học J1;
GUI cấu hình `positive_high=[true,true,false]`. Không tự đảo dấu khi chưa đo.
Z giữ cấp dòng; arm chỉ nhả/giữ bằng lệnh thủ công lúc dừng.

## Home, di chuyển và bảo vệ

Không chạy khi boot. Home quét hai biên Z/J2, thử J1 một đoạn ngắn để đo
beta=dB/dA, dùng beta cho lượt quét dài J1 rồi suy ra hệ số góc theo xung/độ
đã đo. Không dùng tỷ số truyền danh định để ép bù khi J1 chưa được đo.
Các góc tại công tắc và chiều dài L1/L2 do người dùng nhập; chỉ đo xung
không chứng minh góc180° hoặc kích thước98mm là đúng.

Z home3mm/s quy đổi ra4800pps với lead2mm/vòng và vi bước16, trần6400pps
riêng calib Z; chốt/lùi400pps và có ramp. Arm/MOVE/đường vẽ trần1600pps.
PATH/SEG/GO dùng FIFO32 đoạn và profile v² bậc5 fixed-point, đổi DIR sau
khi hạ HIGH, HIGH/DIR setup≥50µs. GUI preflight toàn bộ nét trước khi phát.

Kiểm tra sáu biên ở từng cạnh xung, giới hạn mềm, heartbeat350ms, USB,
GPIO/readback và cạn bộ đệm. STOP/lỗi hủy mốc, không tự tiếp tục sau lỗi.
Số xung là số cạnh đã phát/ghi nhận trong firmware, không phải encoder.

## Build và xác minh

- `tools/build.ps1`: Zephyr SDK0.16.8, Ninja, Python ở `D:/zephyrproject/.venv`.
  Dùng junction đã kiểm tra trỏ về workspace để tránh đường dẫn có dấu cách.
  Dùng `-BuildDirectory build_refactor -SkipExport` để kiểm tra bản sửa trong
  thư mục riêng; bỏ `-SkipExport` khi cần xuất lại bộ HEX/BIN trong `Hex/`.
- `tools/verify.ps1`: build harness C vào `build_host/`, chạy full home,
  GPIO/timer, DDA, giới hạn, USB/watchdog, biên parser/JSON và kiểm thử
  mô hình/giao tiếp. `-CoreOnly` chỉ chạy phần firmware.
- `tools/verify_artifacts.py`: kiểm tra HEX/BIN, vector và RAM. Mặc định chỉ đọc
  bộ phát hành và báo cáo khớp checksum trong `Hex/`. Truyền `--elf` để kiểm tra
  ELF của bản mới; ảnh flash trong ELF phải khớp BIN trước khi dùng số RAM.
  Chỉ ghi báo cáo khi có `--output`, không gắn mã nguồn mới vào báo cáo cũ.
- `build_mcu/`, `build_refactor/`, `build_host/`: sản phẩm sinh lại.

Từ thư mục gốc, chạy `./Verify_SCARA.ps1 -Gui` để kiểm tra firmware trước rồi
toàn bộ software, gồm năm GUI smoke test bằng cổng giả lập. Có thể truyền
`-Python` và `-Gcc`; mặc định tìm công cụ trên PATH rồi thử đường dẫn cài cũ.

Kiểm tra ảnh vừa build mà không thay bộ phát hành:

```powershell
./Firmware/ScaraCartesian/tools/build.ps1 -BuildDirectory build_refactor -SkipExport
D:/zephyrproject/.venv/Scripts/python.exe Firmware/ScaraCartesian/tools/verify_artifacts.py --hex Firmware/ScaraCartesian/build_refactor/zephyr/zephyr.hex --bin Firmware/ScaraCartesian/build_refactor/zephyr/zephyr.bin --elf Firmware/ScaraCartesian/build_refactor/zephyr/zephyr.elf --output Firmware/ScaraCartesian/build_refactor/verification.json
```

Kiểm tra ELF cần `pyelftools`, đã có trong môi trường Python của Zephyr.

`../Ref/` giữ mã CubeMX gốc từng chạy phần cứng, chỉ để tham khảo.
Không còn các dự án jog, HEX hay archive nguồn của phiên bản cũ.

## Cấu trúc mã nguồn

- `src/main.c`: nối phần cứng Zephyr với worker, GPIO/readback, timer ISR,
  callback USB và vòng lặp chính. Mọi thay đổi trạng thái dùng cùng khóa IRQ;
  HIGH được xả hết trước khi đổi DIR hoặc bắt đầu lượt chạy tiếp theo.
- `src/cart_core.c`: bảo vệ công tắc/heartbeat, DDA, FIFO đường vẽ, profile
  tốc độ và các bước home/coupling. `home_worker.c` thực hiện từng lượt đo;
  `jog_core.c` xử lý trạng thái công tắc và bộ phát xung một trục.
- `src/cart_commands.c`: xác nhận session/job, cấu hình và lệnh chuyển trạng
  thái; `cart_core_internal.h` chỉ chia sẻ những chuyển trạng thái cần thiết
  với worker. Giao diện dùng bởi lớp phần cứng vẫn ở `cart_core.h`.
- `src/command_text.c`: token và số nguyên dùng bộ nhớ của caller, không dùng
  con trỏ toàn cục của `strtok`. Grammar riêng của Cartesian và jog được giữ.
- `src/command_stream.c`: nhận lệnh dạng dòng ASCII, giới hạn 191
  byte nội dung, bỏ CR, loại cả dòng lỗi và xóa phần dòng cũ khi USB đổi epoch.
- `src/cart_telemetry.c`: chụp các trường trạng thái trong khóa, định dạng
  status ngoài khóa và tạo JSON ACK. Schema và thứ tự trường protocol5 không
  thay đổi.

`tests/test_protocol.c` kiểm tra chiều dài dòng, byte lỗi, reset session,
giới hạn số nguyên, parser độc lập, ACK chính xác và snapshot không bị thay đổi
sau khi state tiếp tục chạy. `tests/host_firmware.c` vẫn chạy trực tiếp mã
GPIO/timer thực với ngoại vi giả lập, gồm full home và chuyển đoạn đường vẽ.

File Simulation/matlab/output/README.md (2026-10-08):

# Kết quả MATLAB/Simulink

- `figures/`: ảnh 3D, tracking, so sánh PID, sơ đồ Simulink.
- `data/matlab/`: simulation.mat/csv và controller_comparison.mat.
- `data/simulink/`: simulation.mat/csv chạy từ SLX.
- `logs/`: log chạy MATLAB; log cũ trước sắp xếp được giữ để đối chiếu.
- `validation/validation.json`: kiểm chứng đã chạy lại sau sắp xếp.
- `data/matlab/bk/`, `data/simulink/bk/`: CSV/MAT riêng của hình BK.
- `figures/bk_drawing.png`, `bk_tracking.png`: hình BK và đồ thị điều khiển.
- `validation/bk_validation.json`: hình học, nhấc bút và so sánh MATLAB/Simulink BK.
- `cache/`, `codegen/`: file tự sinh của Simulink, không thêm vào source path.

MAT có thể giữ đường dẫn trong biến p từ thời điểm tạo. Hàm mới đọc đường dẫn
theo vị trí project hiện tại; không dùng đường dẫn trong MAT cũ để tìm source.

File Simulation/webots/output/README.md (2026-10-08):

# Kết quả Webots

`runs/<timestamp>/`: dữ liệu thực nghiệm khi chạy Webots, mỗi lần một thư mục.
`validation/`: báo cáo kiểm tra offline. `webots_physics_tested: false` có nghĩa
chưa chạy vật lý Webots; không dùng báo cáo này để kết luận lực/sai số thực tế.

Xem `webots/README.md` để giải thích cột CSV và cách đọc bằng MATLAB.

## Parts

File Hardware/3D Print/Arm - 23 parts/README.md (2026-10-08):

# Arm - 23 parts

| Folder con | File STL | Số bản in |
| --- | --- | ---: |
| Black_Quantity1 | Arm_Elbow_Plate_Bottom_1.0.0.stl | 1 |
| Black_Quantity1 | Arm_Elbow_Plate_Top_1.0.0.stl | 1 |
| Black_Quantity1 | Arm_Shoulder_Plate_Bottom_1.0.0.stl | 1 |
| Black_Quantity1 | Arm_Shoulder_Plate_Top_1.0.0.stl | 1 |
| Black_Quantity2 | Arm_Base_MotorPlate_1.1.2.stl | 2 |
| Black_Quantity2 | Arm_Endstop_1.0.3.stl | 2 |
| Orange_Quantity1 | Arm_Base_ZHub_Bottom_1.0.0.stl | 1 |
| Orange_Quantity1 | Arm_Base_ZHub_Top_1.0.0.stl | 1 |
| Orange_Quantity1 | Arm_Base_ZPlate_Mid_NutHolder_1.0.0.stl | 1 |
| Orange_Quantity1 | Arm_Elbow_RodHub_1.0.0.stl | 1 |
| Orange_Quantity1 | Arm_EMount_Base_ABL_1.1.2.stl | 1 |
| Orange_Quantity1 | Arm_EMount_Base_Left_1.1.2.stl | 1 |
| Orange_Quantity1 | Arm_EMount_Base_Right_1.1.2.stl | 1 |
| Orange_Quantity2 | Arm_Plates_Cover_1.0.0.stl | 2 |
| Orange_Quantity2 | Arm_Shoulder_Connector_1.1.2.stl | 2 |
| Orange_Quantity2 | Arm_SideWall_Left_1.0.0.stl | 2 |
| Orange_Quantity2 | Arm_SideWall_Right_1.0.0.stl | 2 |

**Tổng số bản cần in trong folder này: 23**

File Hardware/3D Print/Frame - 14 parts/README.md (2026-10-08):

# Frame - 14 parts

| Folder con | File STL | Số bản in |
| --- | --- | ---: |
| Black-Quantity4 | Frame_Plate_Side_RodClamp_1.0.0.stl | 4 |
| Black_Quantity1 | Frame_Z_BearingHolder_1.0.2.stl | 1 |
| Black_Quantity1 | Frame_Z_BearingPlate_1.0.0.stl | 1 |
| Black_Quantity1 | Frame_Z_MotorPlate_1.0.0.stl | 1 |
| Orange_Quantity1 | Frame_Z_MotorConnector_1.0.0.stl | 1 |
| Orange_Quantity2 | Frame_Plate_Side_Left_1.1.2.stl | 2 |
| Orange_Quantity2 | Frame_Plate_Side_Right_1.1.2.stl | 2 |
| Orange_Quantity2 | Frame_Plate_TipConnector_1.0.1.stl | 2 |

**Tổng số bản cần in trong folder này: 14**

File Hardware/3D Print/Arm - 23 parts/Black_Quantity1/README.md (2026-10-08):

# Black_Quantity1

**Số loại STL:** 4  
**Số bản cần in trong folder:** 4

| File STL | Số bản in |
| --- | ---: |
| Arm_Elbow_Plate_Bottom_1.0.0.stl | 1 |
| Arm_Elbow_Plate_Top_1.0.0.stl | 1 |
| Arm_Shoulder_Plate_Bottom_1.0.0.stl | 1 |
| Arm_Shoulder_Plate_Top_1.0.0.stl | 1 |

Số lượng là số bản cần in cho từng file STL.

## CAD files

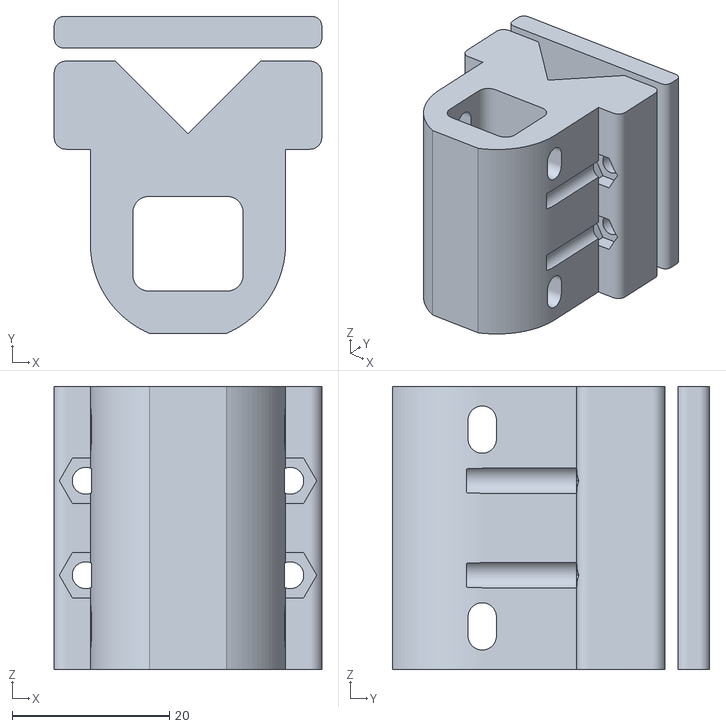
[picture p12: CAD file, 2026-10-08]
Hardware/Pen_Holder_EG118/assembly_reference.stl
34.0 x 40.3 x 36.0

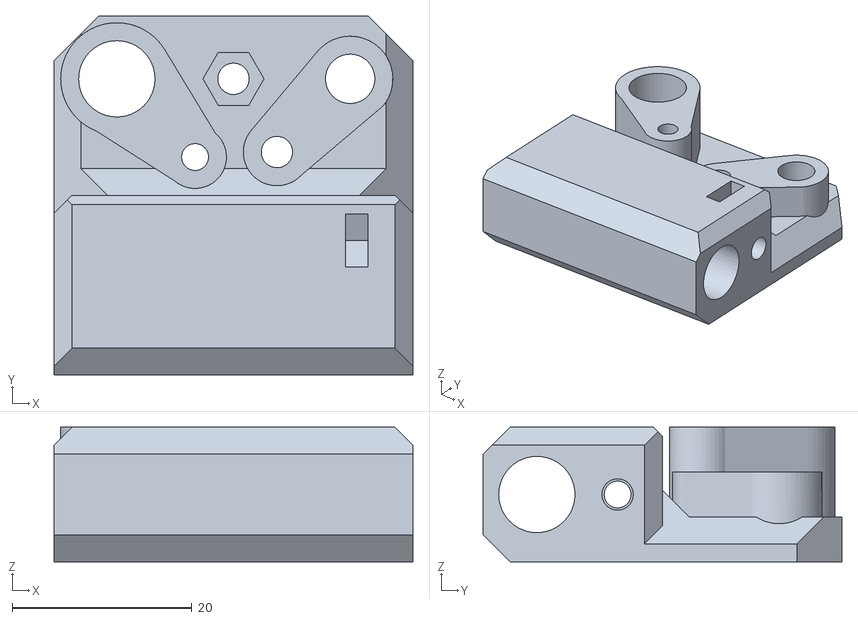
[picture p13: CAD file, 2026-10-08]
Hardware/3D Print/00 - Test Part - 1 part/Test_hardware_fit_1.0.4.stl
40.0 x 40.0 x 15.0

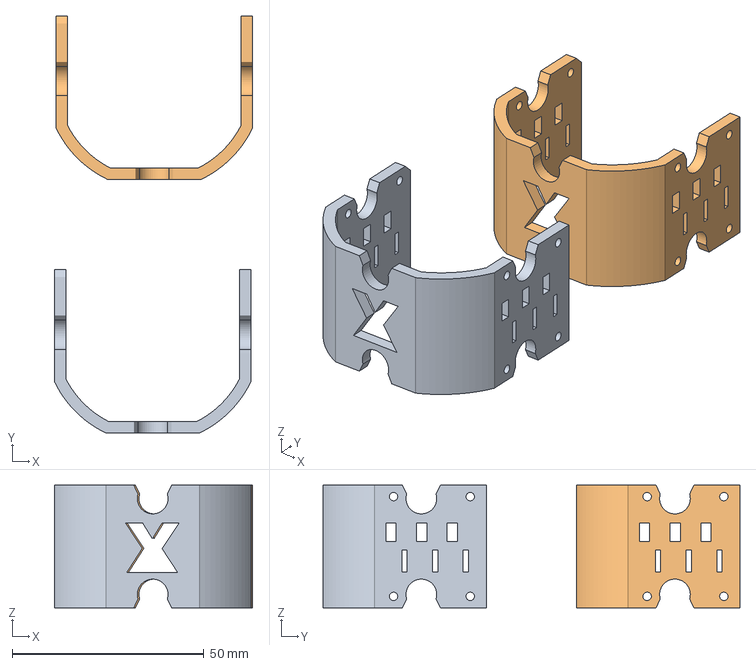
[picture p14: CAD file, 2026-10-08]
Hardware/3D Print/Arm - 23 parts/Arm_Plates_Cover_1.0.0.3mf
51.7 x 108.7 x 32.0 mm
Arm_Plates_Cover_1.0.0.stl x 2

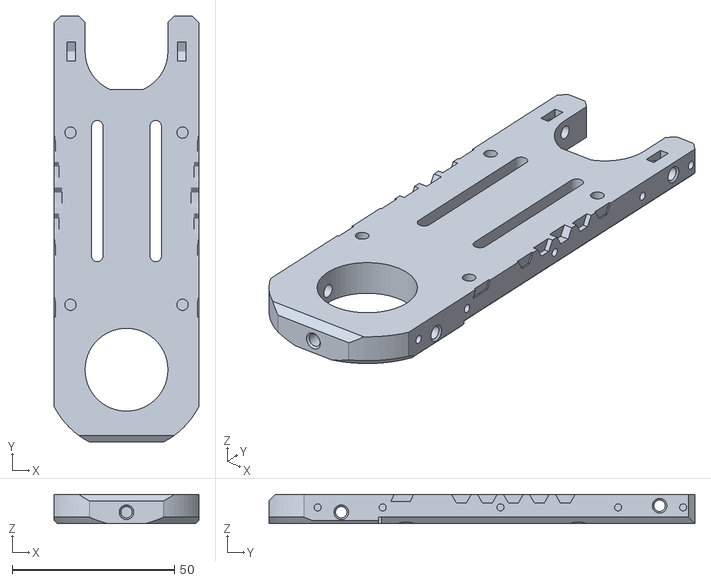
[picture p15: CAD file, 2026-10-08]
Hardware/3D Print/Arm - 23 parts/Black_Quantity1/Arm_Elbow_Plate_Bottom_1.0.0.stl
44.5 x 131.2 x 9.00

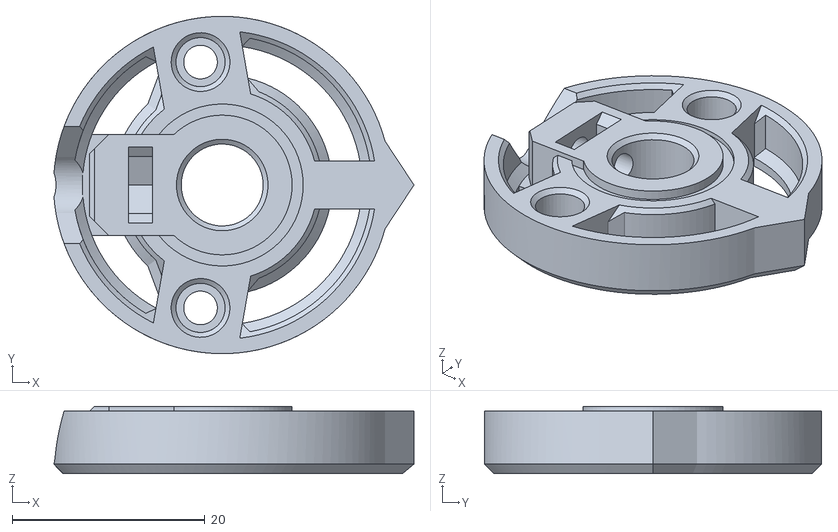
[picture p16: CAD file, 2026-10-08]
Hardware/3D Print/Arm - 23 parts/Black_Quantity2/Arm_Endstop_1.0.3.stl
37.4 x 35.0 x 7.00

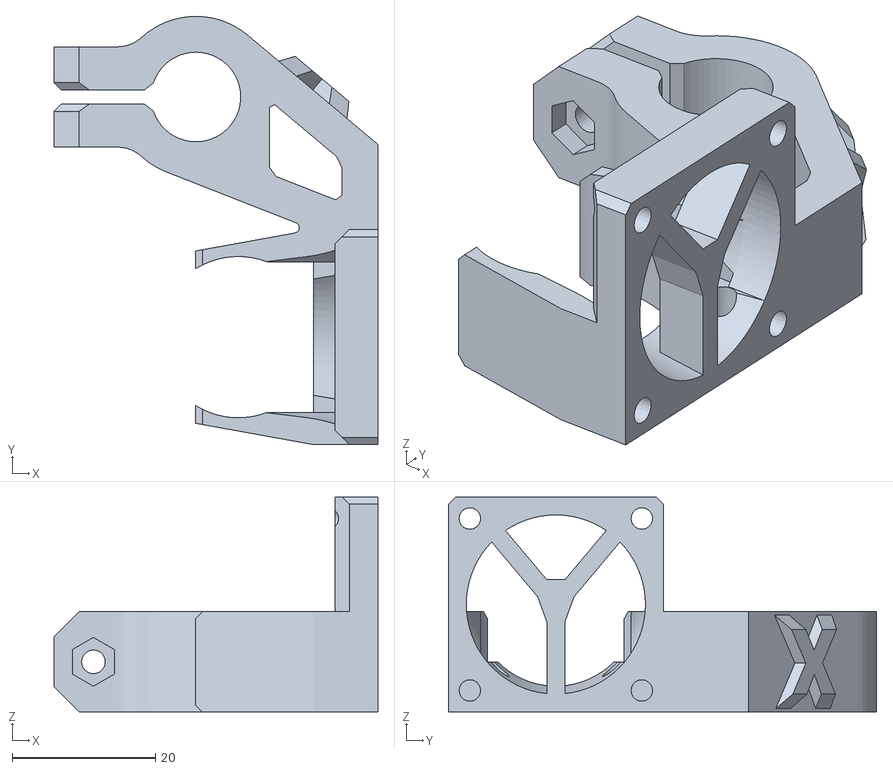
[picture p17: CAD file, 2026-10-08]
Hardware/3D Print/Arm - 23 parts/Orange_Quantity1/Arm_EMount_Base_ABL_1.1.2.stl
45.2 x 59.8 x 30.0

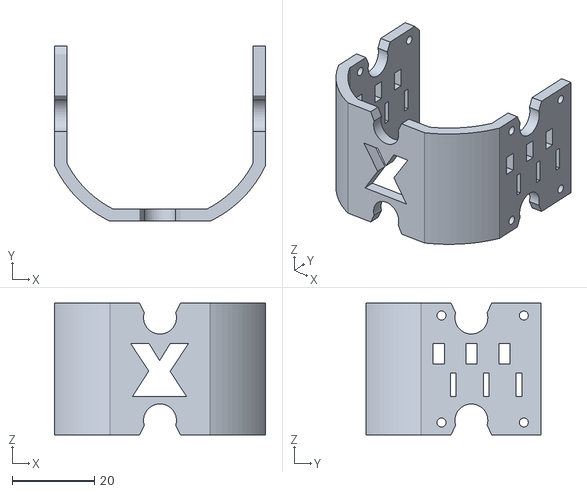
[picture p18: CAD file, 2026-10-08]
Hardware/3D Print/Arm - 23 parts/Orange_Quantity2/Arm_Plates_Cover_1.0.0.stl
51.3 x 42.6 x 32.0

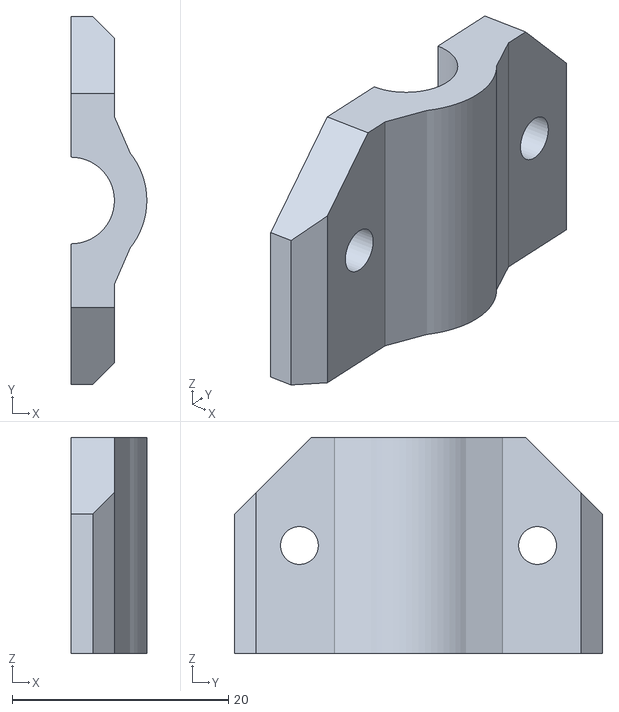
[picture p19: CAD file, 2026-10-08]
Hardware/3D Print/Frame - 14 parts/Black-Quantity4/Frame_Plate_Side_RodClamp_1.0.0.stl
7.00 x 34.0 x 20.0

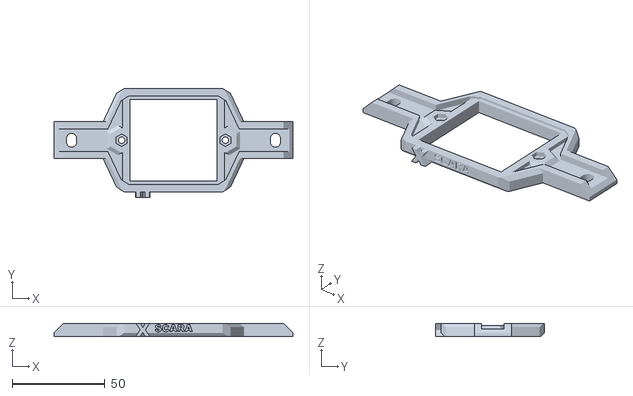
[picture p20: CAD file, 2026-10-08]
Hardware/3D Print/Frame - 14 parts/Black_Quantity1/Frame_Z_MotorPlate_1.0.0.stl
129.0 x 59.0 x 7.03

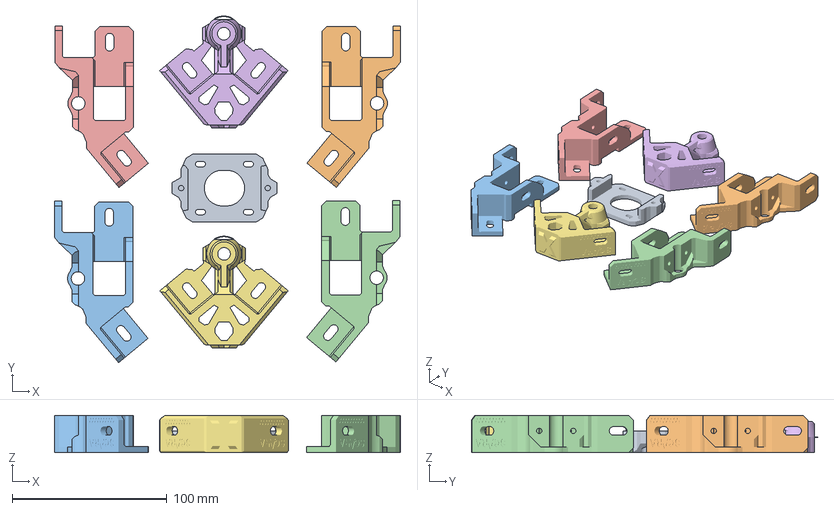
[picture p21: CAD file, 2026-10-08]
Hardware/3D Print/Frame - 14 parts/Orange.3mf
223.7 x 224.0 x 24.0 mm
Frame_Z_MotorConnector_1.0.0.stl
Frame_Plate_Side_Left_1.1.2.stl x 2
Frame_Plate_Side_Right_1.1.2.stl x 2
Frame_Plate_TipConnector_1.0.1.stl x 2

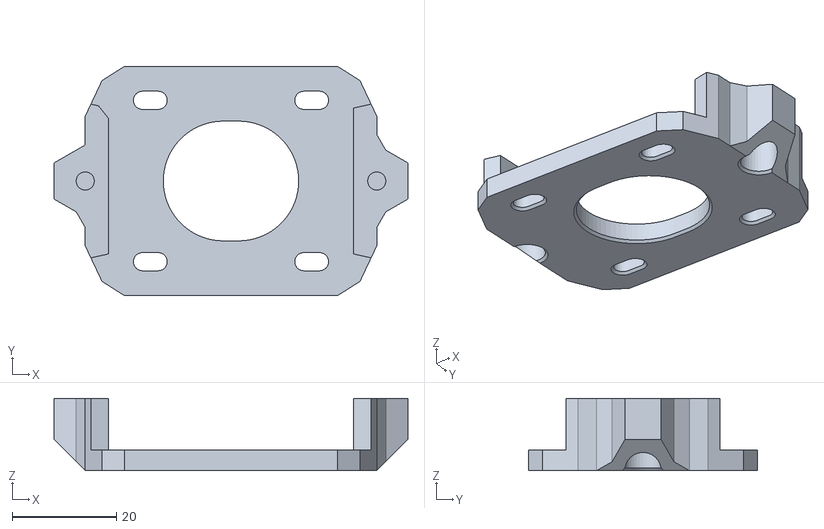
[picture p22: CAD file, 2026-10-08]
Hardware/3D Print/Frame - 14 parts/Orange_Quantity1/Frame_Z_MotorConnector_1.0.0.stl
68.0 x 44.0 x 13.9

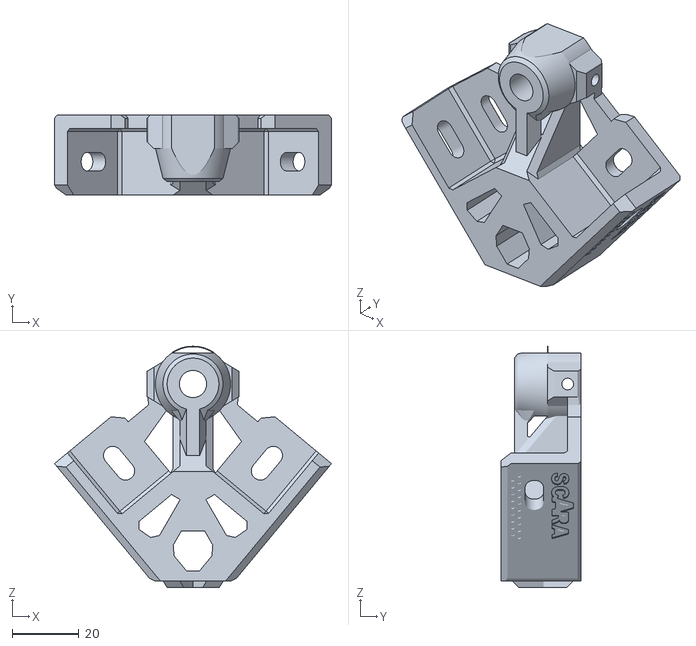
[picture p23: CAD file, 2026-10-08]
Hardware/3D Print/Frame - 14 parts/Orange_Quantity2/Frame_Plate_TipConnector_1.0.1.stl
83.0 x 24.0 x 72.3

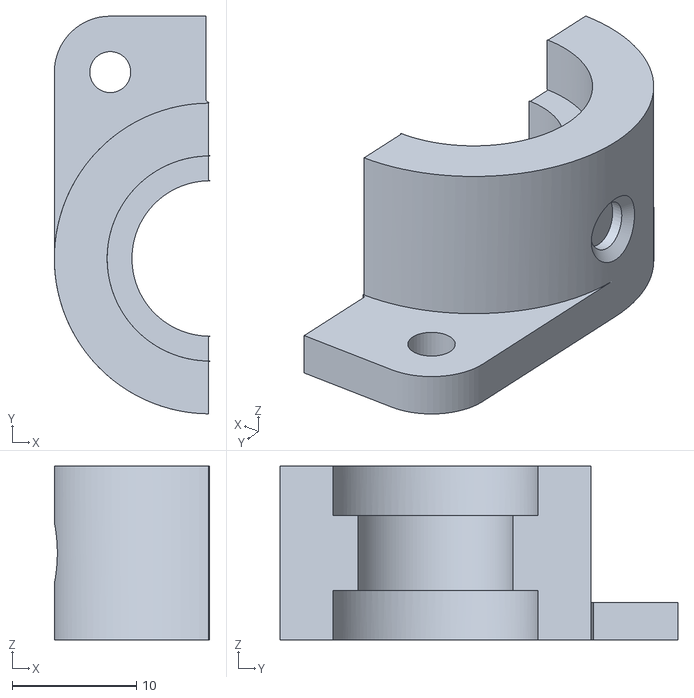
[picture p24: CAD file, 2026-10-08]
Hardware/arm/STL/Orange_Quantity1/Arm_EMount_Base_Right_1.1.2.stl
12.5 x 32.0 x 14.0

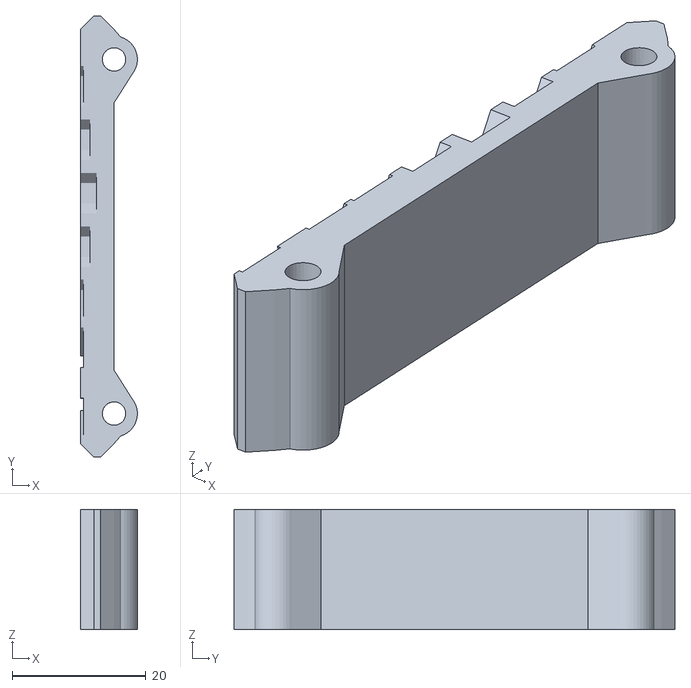
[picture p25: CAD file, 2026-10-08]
Hardware/arm/STL/Orange_Quantity2/Arm_SideWall_Left_1.0.0.stl
8.49 x 66.0 x 18.0

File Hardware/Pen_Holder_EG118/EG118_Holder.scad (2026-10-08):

// SCARA pen holder, revision 1. Units: mm.
// +Y = outward from fork; +Z = up. Pen held by a 90 degree V-saddle.
// Verified barrel range: 8.5 to 9.5 mm; diameter supplied by user: ~9 mm.
// part: "base", "cap_print", "test_base", "test_cap_print", "assembly"
part = "assembly";
pen_diameter = 9.0;
height = 36;
fork_radius = 12.4;
fork_rear_flat = 11.4;
mount_centers_z = [5.5, 30.5];
mount_slot_d = 3.6;
mount_slot_stroke = 2.4;
clamp_hole_d = 3.4;
nut_af = 5.8;
nut_depth = 2.6;
$fn = 96;

pen_y = 14 + pen_diameter / sqrt(2);
pressure_y = pen_y + pen_diameter / 2;

assert(pen_diameter >= 8.5 && pen_diameter <= 9.5,
       "Revision 1: use pen_diameter between 8.5 and 9.5 mm.");

module round_rect(x0,y0,x1,y1,r=1.5) {
    translate([x0+r,y0+r]) offset(r=r,$fn=32)
        square([x1-x0-2*r,y1-y0-2*r]);
}
module tongue_profile() {
    intersection() {
        union() {
            intersection() {
                circle(r=fork_radius);
                translate([-20,-20]) square([40,20]);
            }
            translate([-fork_radius,0]) square([2*fork_radius,13.5]);
        }
        translate([-20,-fork_rear_flat]) square([40,40]);
    }
}
module x_hole(z) {
    translate([-25,0,z]) rotate([0,90,0]) cylinder(h=50,d=mount_slot_d);
}
module y_hole(x,z) {
    translate([x,-2,z]) rotate([-90,0,0]) cylinder(h=44,d=clamp_hole_d);
}
module nut_socket(x,z) {
    translate([x,11.99,z]) rotate([-90,0,0])
        cylinder(h=nut_depth+0.01,r=nut_af/sqrt(3),$fn=6);
}
module base(h=height, coupon=false) {
    difference() {
        linear_extrude(h) union() {
            tongue_profile();
            round_rect(-17,12,17,23.2);
        }
        translate([0,0,-1]) linear_extrude(h+2)
            polygon([[0,14],[22,36],[-22,36]]);
        translate([0,0,-1]) linear_extrude(h+2)
            round_rect(-7,-6,7,6,2);
        for (z=coupon ? [4] : mount_centers_z)
            hull() {
                x_hole(z-mount_slot_stroke/2);
                x_hole(z+mount_slot_stroke/2);
            }
        for (x=[-13,13],z=coupon ? [h/2] : [12,24]) {
            y_hole(x,z);
            nut_socket(x,z);
        }
    }
}
module cap(h=height,coupon=false) {
    difference() {
        linear_extrude(h) round_rect(-17,pressure_y,17,pressure_y+4,1.2);
        for (x=[-13,13],z=coupon ? [h/2] : [12,24]) y_hole(x,z);
    }
}
module cap_on_bed(h=height,coupon=false) {
    translate([17,h,pressure_y+4]) rotate([90,0,0]) cap(h,coupon);
}
if (part=="base") translate([17,fork_rear_flat,0]) base();
else if (part=="cap_print") cap_on_bed();
else if (part=="test_base") translate([17,fork_rear_flat,0]) base(8,true);
else if (part=="test_cap_print") cap_on_bed(8,true);
else if (part=="assembly") {
    color([1,.55,.12]) base();
    color([.1,.65,.6]) cap();
    // Reference barrel only. Do not export this scene for printing.
    %translate([0,pen_y,-17]) cylinder(h=87,d=pen_diameter);
} else assert(false,"Unknown part selector");

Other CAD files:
Hardware/arm/STL/Black_Quantity1/Arm_Elbow_Plate_Top_1.0.0.stl
Hardware/frame/STL/Black_Quantity1/Frame_Z_BearingHolder_1.0.2.stl
Hardware/3D Print/Arm - 23 parts/Black_Quantity1/Arm_Elbow_Plate_Top_1.0.0.stl
Hardware/3D Print/Arm - 23 parts/Black_Quantity1/Arm_Shoulder_Plate_Bottom_1.0.0.stl
Hardware/3D Print/Arm - 23 parts/Black_Quantity1/Arm_Shoulder_Plate_Top_1.0.0.stl
Hardware/3D Print/Arm - 23 parts/Black_Quantity1/BlackQuantity1.3mf
Hardware/3D Print/Arm - 23 parts/Black_Quantity2/Arm_Base_MotorPlate_1.1.2.stl
Hardware/3D Print/Arm - 23 parts/Black_Quantity2/Black_Quantity2.3mf
Hardware/3D Print/Arm - 23 parts/Orange_1_2.3mf
Hardware/3D Print/Arm - 23 parts/Orange_Quantity1/Arm_Base_ZHub_Bottom_1.0.0.stl
Hardware/3D Print/Arm - 23 parts/Orange_Quantity1/Arm_Base_ZHub_Top_1.0.0.stl
Hardware/3D Print/Arm - 23 parts/Orange_Quantity1/Arm_Base_ZPlate_Mid_NutHolder_1.0.0.stl
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

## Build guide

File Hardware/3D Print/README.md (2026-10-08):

# Danh sách file in 3D — X-SCARA

## Tổng số lượng

- **Frame:** 14 chi tiết (8 loại STL).
- **Arm:** 23 chi tiết (17 loại STL).
- **Test part:** 1 chi tiết để in thử trước khi in bộ chính.
- **Tổng:** 38 bản in, gồm 37 chi tiết lắp ráp và 1 mẫu thử.

Các thư mục màu/số lượng giữ theo cách phân loại gốc. `QuantityN` nghĩa là in **N bản của mỗi file STL trong thư mục đó**; ví dụ `Orange_Quantity2` có 4 file, mỗi file in 2 bản (8 chi tiết tổng).

## Frame — 14 chi tiết

| STL | Số lượng |
| --- | ---: |
| Frame_Plate_TipConnector | 2 |
| Frame_Plate_Side_Left | 2 |
| Frame_Plate_Side_Right | 2 |
| Frame_Plate_Side_RodClamp | 4 |
| Frame_Z_BearingPlate | 1 |
| Frame_Z_BearingHolder | 1 |
| Frame_Z_MotorPlate | 1 |
| Frame_Z_MotorConnector | 1 |
| **Cộng** | **14** |

## Arm — 23 chi tiết

| STL | Số lượng |
| --- | ---: |
| Arm_Base_MotorPlate | 2 |
| Arm_Base_ZPlate_Mid_NutHolder | 1 |
| Arm_Base_ZHub_Top | 1 |
| Arm_Base_ZHub_Bottom | 1 |
| Arm_Shoulder_Plate_Top | 1 |
| Arm_Shoulder_Plate_Bottom | 1 |
| Arm_SideWall_Left (Arm) | 2 |
| Arm_SideWall_Right (Arm) | 2 |
| Arm_Plates_Cover | 2 |
| Arm_Shoulder_Connector | 2 |
| Arm_Elbow_Plate_Top | 1 |
| Arm_Elbow_Plate_Bottom | 1 |
| Arm_Elbow_RodHub | 1 |
| Arm_EMount_Base_ABL | 1 |
| Arm_EMount_Base_Left | 1 |
| Arm_EMount_Base_Right | 1 |
| Arm_Endstop | 2 |
| **Cộng** | **23** |

`Arm_SideWall_Left` và `Arm_SideWall_Right` cần 2 bản mỗi loại: mỗi bên một bản cho Shoulder và một bản cho Elbow.

## In thử

In **1** bản `Test_hardware_fit_1.0.4.stl` trước để kiểm tra độ khớp với thanh M8, vít/ê-cu M3 và vít M5; sau đó mới in Frame và Arm.

## Nguồn số lượng

- [X-SCARA Frame README trên GitHub](https://github.com/madl3x/x-scara/blob/master/hardware/frame/README.md)
- `../frame/BOM.md` và `../arm/BOM.md` trong workspace.
- `../Hướng dẫn in test part và số lượng.docx` trong workspace.

## README theo từng folder

Mỗi folder Frame, Arm, Test Part và từng folder số lượng đều có README.md riêng liệt kê chính xác file STL và số bản cần in.

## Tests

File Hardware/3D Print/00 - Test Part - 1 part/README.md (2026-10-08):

# 00 - Test Part - 1 part

**Số loại STL:** 1  
**Số bản cần in trong folder:** 1

| File STL | Số bản in |
| --- | ---: |
| Test_hardware_fit_1.0.4.stl | 1 |

Số lượng là số bản cần in cho từng file STL.

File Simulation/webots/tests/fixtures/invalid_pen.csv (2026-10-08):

x_mm | y_mm | pen
0 | 0 | 0
1 | 1 | 0.5

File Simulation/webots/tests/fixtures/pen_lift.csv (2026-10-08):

x_mm | y_mm | pen
-10 | 0 | 0
10 | 0 | 0
10 | 10 | 1

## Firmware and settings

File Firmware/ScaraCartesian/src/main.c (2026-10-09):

/* Three-axis NC home/calibration and coordinated Cartesian motor execution. */
#include <zephyr/kernel.h>
#include <zephyr/drivers/counter.h>
#include <zephyr/drivers/gpio.h>
#include <zephyr/drivers/uart.h>
#include <zephyr/usb/usb_device.h>
#include <zephyr/irq.h>
#include <string.h>
#include "cart_core.h"
#include "cart_telemetry.h"
#include "command_stream.h"
#include "command_text.h"
#define USER_NODE DT_PATH(zephyr_user)
#define PULSE_HIGH_US 50U
struct motor_pins { struct gpio_dt_spec p, d, e; };
static const struct motor_pins motors[CT_AXES] = {
    { GPIO_DT_SPEC_GET(USER_NODE, pul_gpios), GPIO_DT_SPEC_GET(USER_NODE, dir_gpios), GPIO_DT_SPEC_GET(USER_NODE, ena_gpios) },
    { GPIO_DT_SPEC_GET(USER_NODE, j1_pul_gpios), GPIO_DT_SPEC_GET(USER_NODE, j1_dir_gpios), GPIO_DT_SPEC_GET(USER_NODE, j1_ena_gpios) },
    { GPIO_DT_SPEC_GET(USER_NODE, j2_pul_gpios), GPIO_DT_SPEC_GET(USER_NODE, j2_dir_gpios), GPIO_DT_SPEC_GET(USER_NODE, j2_ena_gpios) },
};
static const struct gpio_dt_spec limits[CT_AXES][2] = {
    { GPIO_DT_SPEC_GET(USER_NODE, z_pos_gpios), GPIO_DT_SPEC_GET(USER_NODE, z_neg_gpios) },
    { GPIO_DT_SPEC_GET(USER_NODE, j1_pos_gpios), GPIO_DT_SPEC_GET(USER_NODE, j1_neg_gpios) },
    { GPIO_DT_SPEC_GET(USER_NODE, j2_pos_gpios), GPIO_DT_SPEC_GET(USER_NODE, j2_neg_gpios) },
};
static struct ct_state control;
static const struct gpio_dt_spec led = GPIO_DT_SPEC_GET(DT_ALIAS(led0), gpios);
static const struct device *const usb = DEVICE_DT_GET(DT_CHOSEN(zephyr_console));
static const struct device *const timer = DEVICE_DT_GET(DT_NODELABEL(jog_timer));
static uint32_t timer_hz, usb_epoch, pulse_start_cycles, low_us, timer_late;
static unsigned high_mask;
static bool timer_running, usb_configured;
static int motor_error, timer_errno;
static void read_limits(void)
{
    for (unsigned a = 0; a < CT_AXES; a++) {
        gpio_port_value_t bits = 0;
        int error = gpio_port_get_raw(limits[a][0].port, &bits);
        ct_sample(&control, a, error ? error : (int)((bits >> limits[a][0].pin) & 1U),
            error ? error : (int)((bits >> limits[a][1].pin) & 1U), k_uptime_get_32());
    }
}
static void wait_minimum_high(void)
{
    if (!high_mask) return;
    uint32_t elapsed = k_cyc_to_us_floor32(k_cycle_get_32() - pulse_start_cycles);
    if (elapsed < PULSE_HIGH_US) k_busy_wait(PULSE_HIGH_US - elapsed);
}
/* Stop GPIO only: ordinary CAL endpoint stops must retain the worker state. */
static void stop_pulses(void)
{
    counter_stop(timer); timer_running = false;
    wait_minimum_high();
    for (unsigned a = 0; a < CT_AXES; a++) {
        int error = gpio_pin_set_dt(&motors[a].p, 0);
        k_busy_wait(2);
        if (error || gpio_pin_get_raw(motors[a].p.port, motors[a].p.pin) != 0) {
            if (!motor_error) motor_error = 4;
            control.fault = true; ct_abort(&control, "motor_gpio_error");
        }
    }
    high_mask = 0;
}
static void halt(const char *reason)
{ ct_abort(&control, reason); stop_pulses(); }
static bool pin_level(const struct gpio_dt_spec *p, int expected, int fault)
{
    if (gpio_pin_get_raw(p->port, p->pin) == expected) return true;
    if (!motor_error) motor_error = fault;
    control.fault = true; halt("motor_gpio_error"); return false;
}
static bool write_level(const struct gpio_dt_spec *p, int value, int fault)
{
    if (gpio_pin_set_dt(p, value)) {
        if (!motor_error) motor_error = fault;
        control.fault = true; halt("motor_gpio_error"); return false;
    }
    k_busy_wait(2); return pin_level(p, value, fault);
}
static int direction_level(unsigned a)
{ return (control.direction[a] > 0) == control.pol[a]; }
static void pulse_tick(const struct device *dev, void *data);
static int timer_period(uint32_t us, bool reset)
{
    struct counter_top_cfg cfg = {
        .ticks = (uint32_t)(((uint64_t)timer_hz * us) / 1000000U) - 1U,
        .callback = pulse_tick,
        .flags = reset ? 0 : COUNTER_TOP_CFG_DONT_RESET | COUNTER_TOP_CFG_RESET_WHEN_LATE,
    };
    int error = counter_set_top_value(timer, &cfg);
    if (error == -ETIME && !reset) { if (timer_late < UINT32_MAX) timer_late++; return 0; }
    if (error) timer_errno = error;
    return error;
}
static void timer_fault(void)
{ control.fault = true; halt("timer_error"); }
static void pulse_tick(const struct device *dev, void *data)
{
    (void)dev; (void)data;
    unsigned key = irq_lock();
    if (motor_error) { halt("motor_gpio_error"); goto out; }
    read_limits(); /* Timestamp must follow GPIO reads, including across ms wrap. */
    if (high_mask) {
        wait_minimum_high();
        unsigned mask = high_mask;
        for (unsigned a = 0; a < CT_AXES; a++)
            if ((mask & (1U << a)) && !write_level(&motors[a].p, 0, 4)) goto out;
        high_mask = 0;
        if (control.path_active && control.path_started && control.tick==control.ticks) {
            if (!ct_path_advance(&control)) { stop_pulses(); goto out; }
            if (!ct_safe(&control,k_uptime_get_32())) { stop_pulses(); goto out; }
            for (unsigned a=0;a<CT_AXES;a++)
                if (control.direction[a] && !write_level(&motors[a].d,direction_level(a),1)) goto out;
            /* LOW is >=312 us at 1600pps: DIR has >=50us setup before
             * the next edge, without restarting the timer or a 50ms pause. */
            if (low_us<100U) low_us=100U;
        }
        if (!control.running || !ct_safe(&control, k_uptime_get_32())) { stop_pulses(); goto out; }
        if (timer_period(low_us, false)) timer_fault();
        goto out;
    }
    if (!ct_safe(&control, k_uptime_get_32())) { stop_pulses(); goto out; }
    for (unsigned a = 0; a < CT_AXES; a++) {
        if (!pin_level(&motors[a].e, 0, 2) || !pin_level(&motors[a].p, 0, 4)) goto out;
        if (control.direction[a] && !pin_level(&motors[a].d, direction_level(a), 1)) goto out;
    }
    uint32_t period = ct_period_us(&control, k_uptime_get_32()), high_us = period / 2U;
    low_us = period - high_us;
    unsigned mask = ct_next_mask(&control);
    if (!control.running) { stop_pulses(); goto out; }
    for (unsigned a = 0; a < CT_AXES; a++) if (mask & (1U << a)) {
        high_mask |= 1U << a; pulse_start_cycles = k_cycle_get_32();
        if (!write_level(&motors[a].p, 1, 3)) goto out;
        pulse_start_cycles = k_cycle_get_32();
        ct_count(&control, a);
    }
    ct_finish_tick(&control);
    /* Even the final rising edge drains HIGH before a new direction/leg. */
    if (timer_period(high_us, false)) timer_fault();
out:
    irq_unlock(key);
}
static void start_motor(void)
{
    bool ok = !motor_error && !timer_running && !high_mask;
    for (unsigned a = 0; a < CT_AXES && ok; a++) {
        ok = pin_level(&motors[a].p, 0, 4) && pin_level(&motors[a].e, 0, 2);
        if (ok && control.direction[a]) ok = write_level(&motors[a].d, direction_level(a), 1);
    }
    if (!ok) { halt("motor_gpio_error"); return; }
    if (timer_period(ZJ_SETUP_MS * 1000U, true) || counter_start(timer)) timer_fault();
    else timer_running = true;
}
static void sensor_thread(void *a, void *b, void *c)
{
    (void)a; (void)b; (void)c;
    while (1) {
        unsigned key = irq_lock(); read_limits();
        bool indicator = false;
        for (unsigned i = 0; i < CT_AXES; i++) indicator |= control.sw[i].top || control.sw[i].bottom || control.sw[i].conflict;
        gpio_pin_set_dt(&led, indicator);
        if (timer_running && (!control.running || !ct_safe(&control, k_uptime_get_32()))) stop_pulses();
        irq_unlock(key); k_msleep(2);
    }
}
K_THREAD_DEFINE(sensor_tid, 1024, sensor_thread, NULL, NULL, NULL, -1, 0, SYS_FOREVER_MS);
static void usb_status(enum usb_dc_status_code code, const uint8_t *param)
{
    (void)param; unsigned key = irq_lock();
    if (code == USB_DC_CONFIGURED || code == USB_DC_RESUME) usb_configured = true;
    if (code == USB_DC_DISCONNECTED || code == USB_DC_RESET || code == USB_DC_SUSPEND || code == USB_DC_ERROR) {
        usb_configured = false; usb_epoch++; control.session = 0; halt("usb_lost");
    }
    irq_unlock(key);
}
static void output_line(const char *s)
{ if (usb_configured) for (; *s; s++) uart_poll_out(usb, (unsigned char)*s); }
static void status_report(void)
{
    char output[CT_STATUS_CAPACITY];
    struct ct_status status;
    unsigned key = irq_lock();
    ct_status_capture(&status, &control, timer_running, timer_late, k_uptime_get_32());
    for (unsigned a = 0; a < CT_AXES; a++)
        status.dir_levels |= (gpio_pin_get_raw(motors[a].d.port, motors[a].d.pin) == 1 ? 1U : 0U) << a;
    status.motor_error = motor_error;
    status.timer_error = timer_errno;
    irq_unlock(key);
    int n = ct_status_format(output, sizeof(output), &status, k_uptime_get_32());
    if (n > 0 && (size_t)n < sizeof(output)) output_line(output);
}
static void command(const char *line)
{
    unsigned key = irq_lock();
    if (!usb_configured) { halt("usb_lost"); irq_unlock(key); return; }
    read_limits();
    if (timer_running && !control.running) stop_pulses();
    enum ct_result result = ct_command(&control, line, k_uptime_get_32());
    if (result == CT_HOLD_CHANGE) {
        unsigned a = control.hold_axis; bool success = false;
        if (!motor_error && !timer_running && !high_mask && pin_level(&motors[a].p, 0, 4)) {
            int error = gpio_pin_set_dt(&motors[a].e, control.hold_value);
            k_busy_wait(2);
            if (!error) success = pin_level(&motors[a].e, control.hold_value ? 0 : 1, 2);
        }
        ct_hold_complete(&control, success);
        if (!success) { stop_pulses(); result = CT_REJECTED; control.reply = "motor_fault"; }
    } else if (result == CT_START) {
        start_motor();
        if (control.fault) { result = CT_REJECTED; control.reply = control.reason; }
    } else if (!control.running && timer_running) stop_pulses();
    char op[16], output[CT_ACK_CAPACITY];
    command_operation(line, op);
    ct_ack_format(output, sizeof(output), control.session, control.job,
        op, result != CT_REJECTED, control.reply);
    irq_unlock(key);
    if (strcmp(op, "KEEP")) output_line(output);
}
int main(void)
{
    ct_init(&control);
    if (!gpio_is_ready_dt(&led) || !device_is_ready(timer) || !device_is_ready(usb)) return 0;
    for (unsigned a = 0; a < CT_AXES; a++) {
        const struct motor_pins *m = &motors[a];
        if (!gpio_is_ready_dt(&m->p) || !gpio_is_ready_dt(&m->d) || !gpio_is_ready_dt(&m->e) ||
            gpio_pin_configure_dt(&m->p, GPIO_OUTPUT_INACTIVE) || gpio_pin_configure_dt(&m->d, GPIO_OUTPUT_INACTIVE) ||
            gpio_pin_configure_dt(&m->e, GPIO_OUTPUT_ACTIVE)) return 0;
        for (unsigned i = 0; i < 2; i++)
            if (!gpio_is_ready_dt(&limits[a][i]) || gpio_pin_configure_dt(&limits[a][i], GPIO_INPUT | GPIO_PULL_UP)) return 0;
    }
    if (gpio_pin_configure_dt(&led, GPIO_OUTPUT_INACTIVE)) return 0;
    timer_hz = counter_get_frequency(timer);
    if (timer_hz != 1000000U) { motor_error = 5; timer_fault(); }
    k_thread_start(sensor_tid);
    if (usb_enable(usb_status)) return 0;
    struct command_stream receiver = {0};
    uint32_t rx_epoch = 0, report_ms = 0;
    while (1) {
        unsigned char ch; unsigned key = irq_lock();
        uint32_t epoch = usb_epoch; bool connected = usb_configured; irq_unlock(key);
        if (rx_epoch != epoch || !connected) {
            command_stream_reset(&receiver); rx_epoch = epoch;
            while (uart_poll_in(usb, &ch) == 0) {}
        }
        for (unsigned n = 0; n < 256 && uart_poll_in(usb, &ch) == 0; n++) {
            enum command_stream_result received = command_stream_feed(&receiver, ch);
            if (received == COMMAND_COMPLETE) command(receiver.line);
            else if (received == COMMAND_INVALID) {
                key = irq_lock(); halt("invalid_command"); irq_unlock(key);
            }
        }
        key = irq_lock();
        read_limits();
        if (timer_running && (!control.running || !ct_safe(&control, k_uptime_get_32()))) stop_pulses();
        /* Worker may update a backoff target while LOW; DIR changes only idle. */
        if (!high_mask) {
            enum ct_result result = ct_service(&control, k_uptime_get_32());
            if (result == CT_START) start_motor();
            else if (!control.running && timer_running) stop_pulses();
        }
        irq_unlock(key);
        uint32_t now = k_uptime_get_32();
        if (now - report_ms >= 100U) { report_ms = now; status_report(); }
        k_msleep(2);
    }
    return 0;
}

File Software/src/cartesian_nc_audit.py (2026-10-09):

"""Read-only audit of recorded commands/telemetry; no serial ports are opened."""

from pathlib import Path
from dataclasses import asdict
import argparse, json, math
from cartesian_nc_model import NCConfig
from cartesian_nc_protocol import NCStatus
from cartesian_nc_drawing import BKSettings, compile_bk


def audit_log(path):
    config = None
    state = None
    current = None
    drawing_index = -1
    strokes = {}
    drawings = []
    homes = []
    warnings = []
    status_count = 0
    rejected = 0
    last_home_epoch = None
    with Path(path).open(encoding="utf-8") as stream:
        for line in stream:
            try:
                event = json.loads(line)
            except ValueError:
                rejected += 1
                continue
            kind = event.get("type")
            if kind == "connection":
                if event.get("demo"):
                    return {"file": str(path), "demo": True, "drawings": []}
                config = NCConfig.from_dict(event["config"])
            elif kind == "status":
                data = event["status"]
                state = NCStatus(
                    **{
                        k: tuple(v) if isinstance(v, list) else v
                        for k, v in data.items()
                    }
                )
                status_count += 1
                if (
                    state.referenced
                    and state.stage == 8
                    and state.epoch != last_home_epoch
                ):
                    last_home_epoch = state.epoch
                    homes.append(
                        dict(
                            epoch=state.epoch,
                            factors_pp_unit=[v / 1024 for v in state.factor],
                            range=list(state.range),
                            n1=list(state.n1),
                            n2=list(state.n2),
                            coupling=state.coupling_ppm / 1000000,
                            beta=state.beta_q / 1048576,
                            probe_da=state.probe_da,
                            probe_db=state.probe_db,
                            timer_late=state.timer_late,
                        )
                    )
            elif kind == "rx_rejected":
                rejected += 1
            elif kind == "drawing_start" and config and state:
                drawing_index += 1
                current = event["settings"]
                model = config.model(state)
                program = compile_bk(
                    model, state.pos, BKSettings(**current), event.get("dry", False)
                )
                drawings.append(
                    dict(
                        pattern=current["pattern"],
                        settings=current,
                        model_error_mm=program.max_model_error_mm,
                        strokes=[],
                        completed=False,
                        timer_late_at_start=state.timer_late,
                        measured_factors=list(model.factors),
                        coupling=model.coupling,
                    )
                )
            elif kind == "stroke_start" and state and current:
                profiles = event["profiles"]
                start = tuple(state.pos)
                end = tuple(profiles[-1]["steps"])
                position = start
                reversals = [0, 0, 0]
                previous = [0, 0, 0]
                expected = [0, 0, 0]
                for segment in profiles:
                    delta = [b - a for a, b in zip(position, segment["steps"])]
                    for i, d in enumerate(delta):
                        expected[i] += abs(d)
                        sign = (d > 0) - (d < 0)
                        if sign and previous[i] and sign != previous[i]:
                            reversals[i] += 1
                        if sign:
                            previous[i] = sign
                    position = tuple(segment["steps"])
                record = dict(
                    job=event["job"],
                    start_steps=list(start),
                    target_steps=list(end),
                    commanded_closed=start == end,
                    segments=len(profiles),
                    expected_axis_pulses=expected,
                    direction_reversals=reversals,
                    constant_z=all(s["steps"][0] == start[0] for s in profiles),
                    timer_late_at_start=state.timer_late,
                    start_total=list(state.total),
                )
                strokes[event["job"]] = record
                drawings[drawing_index]["strokes"].append(record)
            elif kind == "stroke_complete" and event["job"] in strokes:
                record = strokes[event["job"]]
                record.update(
                    end_steps=event["pos"],
                    step_endpoint_error=[
                        a - b for a, b in zip(event["pos"], record["target_steps"])
                    ],
                    timer_late_delta=event["timer_late"]
                    - record["timer_late_at_start"],
                    starved=event["starved"],
                    elapsed_s=event["elapsed_s"],
                    predicted_s=event["estimated_s"],
                )
                if state and state.job == event["job"]:
                    counted = [
                        a - b for a, b in zip(state.total, record["start_total"])
                    ]
                    record["reported_axis_pulses"] = counted
                    record["axis_pulse_error"] = [
                        a - b for a, b in zip(counted, record["expected_axis_pulses"])
                    ]
            elif kind == "drawing_complete" and drawing_index >= 0:
                drawings[drawing_index].update(
                    completed=True,
                    elapsed_s=event["elapsed_s"],
                    timer_late_at_end=event["status"]["timer_late"],
                    starved=event["status"]["starved"],
                )
    if config:
        warnings.append(
            "Measured pulse/angle factors assume the configured switch endpoint angles; those angles were not measured by this log."
        )
        warnings.append(
            "Telemetry counts commanded pulses, not encoder position. Backlash, missed driver pulses/steps, pen flex/contact and actual dimensions are not measured."
        )
    return dict(
        file=str(Path(path).resolve()),
        demo=False,
        config=asdict(config) if config else None,
        status_frames=status_count,
        rejected_frames=rejected,
        home=homes,
        drawings=drawings,
        limitations=warnings,
    )
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

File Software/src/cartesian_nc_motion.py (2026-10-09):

"""Validated moves, setpoint automation and continuous stroke uploads for NCApp."""

from dataclasses import asdict
import time
from cartesian_nc_workspace import bounded_pose, validate_program
from cartesian_nc_path import PathUpload
from cartesian_nc_shapes import PATTERNS


class MotionController:
    def initialize(self):
        if not self.operable() or self.state.holding != 7:
            return
        self.clear_automation()
        self.local_reference = False
        self.model = None
        self.preview = None
        self.expect_epoch = self.state.epoch + 1
        self.job = max(self.job, self.state.job) + 1
        self.task_kind = "INIT"
        self.trace_event("home_start", config=asdict(self.config), job=self.job)
        self.sequence(
            self.config.commands(self.link.session)
            + [f"INIT {self.link.session} {self.job}"]
        )
        self.message.set(
            "Robot sẽ chạy đến các công tắc để đo; Esc/Dừng hủy ngay. "
            + (
                "Home tiếp tục khi đổi cửa sổ; biên và mất kết nối vẫn được bảo vệ."
                if self.config.home_in_background
                else "Giữ cửa sổ này ở phía trước."
            )
        )
        self.render()

    def get_plan(self):
        if not self.fresh() or not self.local_reference or not self.model:
            raise ValueError("Cần HOME + CALIB trước.")
        return self.model.plan(
            self.state.pos,
            tuple(float(v.get()) for v in self.xyz),
            float(self.speed.get()),
        )

    def preview_target(self):
        self.start_plan(False)

    def move(self):
        self.start_plan(True)

    def start_plan(self, moving, target=None, speed=None, purpose="manual", revision=0):
        if not self.operable() or not self.local_reference or not self.model:
            return
        try:
            target = (
                tuple(float(v.get()) for v in self.xyz)
                if target is None
                else tuple(target)
            )
            speed = float(self.speed.get()) if speed is None else speed
        except ValueError as e:
            self.message.set(str(e))
            return
        if purpose == "manual":
            self.clear_automation()
        self.submit_planning(
            lambda model, start, cancelled: model.plan(start, target, speed),
            purpose=purpose,
            moving=moving,
            revision=revision,
            name="SCARA path validation",
        )
        self.message.set("Đang kiểm tra đường đi và từng bước DDA…")
        self.render()

    def clear_automation(self):
        self.path_upload = None
        self.path_run = None
        self.bk_active = False
        self.bk_pending = False
        self.follow_enabled.set(False)
        self.follow_target = None
        self.follow_revision += 1
        self.program_points = ()
        self.program_index = 0
        self.program_wait = 0

    def toggle_follow(self):
        if not self.follow_enabled.get():
            self.follow_target = None
            self.follow_revision += 1
            if self.active_purpose == "follow":
                self.stop()
            return
        if not self.operable() or not self.local_reference or self.program_points:
            self.follow_enabled.set(False)
            self.message.set("Cần lấy mốc và dừng trước khi bật bám mô hình.")
            return
        self.message.set(
            "Bám mô hình đã bật. Kéo đầu công tác, khuỷu hoặc thanh trượt để điều khiển."
        )
        self.trace_event("follow_enabled")

    def start_program(self):
        if (
            not self.operable()
            or not self.local_reference
            or not self.points
            or self.program_points
        ):
            return
        self.clear_automation()
        points = tuple(self.points)

        def calculate(model, start, cancelled):
            validate_program(model, start, points, cancelled)
            return points

        self.submit_planning(
            calculate, purpose="program_check", name="SCARA setpoint validation"
        )
        self.message.set(f"Đang kiểm tra toàn bộ{len(points)} điểm và đường đi…")

    def finish_program_point(self, now):
        point = self.program_points[self.program_index]
        drawing = self.bk_active
        mode = self.bk_active_plan.dry if drawing else False
        self.record_bk(self.state, True)
        self.trace_event(
            "setpoint_complete",
            index=self.program_index,
            point=asdict(point),
            status=asdict(self.state),
        )
        self.program_index += 1
        self.program_wait = now + point.dwell_s
        if self.program_index == len(self.program_points):
            self.program_points = ()
            self.message.set("Đã hoàn thành chuỗi setpoint.")
            if drawing:
                self.bk_active = False
                pattern = PATTERNS[self.bk_active_plan.settings.pattern][0]
                message = (
                    f"Đã chạy khô {pattern}; bút ở Z nâng."
                    if mode
                    else f"Đã vẽ {pattern} theo xung; bút đã nâng."
                )
                self.message.set(message)
                self.bk_note.set(message)
                elapsed = now - self.bk_started
                self.bk_note.set(message + f" Tổng thời gian {elapsed:.1f}s.")
                self.trace_event(
                    "drawing_complete",
                    dry=mode,
                    elapsed_s=elapsed,
                    status=asdict(self.state),
                )
        else:
            self.message.set(
                f"Đã đến{point.name}; nghỉ{point.dwell_s:g}s trước điểm tiếp theo."
            )
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

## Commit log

2026-10-08 Initial commit: SCARA drawing robot
    Firmware (Zephyr, STM32F103C8), Python GUI with IK path planning,
    MATLAB/Simulink and Webots simulation, and 3D-printed hardware based
    on madl3x/x-scara (GPL-3.0).
    [01_Fork_Adapter_V_Saddle.stl, 02_Pressure_Cap.stl, 03_Test_Adapter_8mm.stl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]
2026-10-08 Add real robot photos and drawing demo video
    Web-optimized copies (resized, EXIF stripped) of the hardware photos
    and the flower-drawing video, plus a GIF preview shown in the README.
2026-10-08 Rewrite README in English and Vietnamese
    English section first, Vietnamese section below, with a language
    switcher at the top.
2026-10-09 Refactor firmware and control software
    Extract command parsing, USB framing and telemetry from the motion core. Separate GUI connection, planning, motion, safety and view logic, fix USB-disconnect event handling, and add unified verification. Preserve verified R9 firmware artifacts with exact HEX bytes. Validated 68 unit tests, three C harnesses, five GUI smoke tests, the STM32 build and packaged offline smoke.
    [cart_telemetry.c, cartesian_model.py, cartesian_nc_audit.py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]
